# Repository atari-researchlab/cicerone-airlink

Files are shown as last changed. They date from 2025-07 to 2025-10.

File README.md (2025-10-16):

<!-- LICENSE INFORMATION
Copyright (C) 2025 ATARI Research Lab
Permission is granted to copy, distribute and/or modify this document
under the terms of the GNU Free Documentation License, Version 1.3
or any later version published by the Free Software Foundation;
with no Invariant Sections, no Front-Cover Texts, and no Back-Cover Texts.
A copy of the license is included in the section entitled "GNU
Free Documentation License".
-->

<!-- markdownlint-disable MD041 MD013 -->

<p align="center">
  Grant <strong><em>PID2021-126810OB-I00</em></strong> funded by:<br />
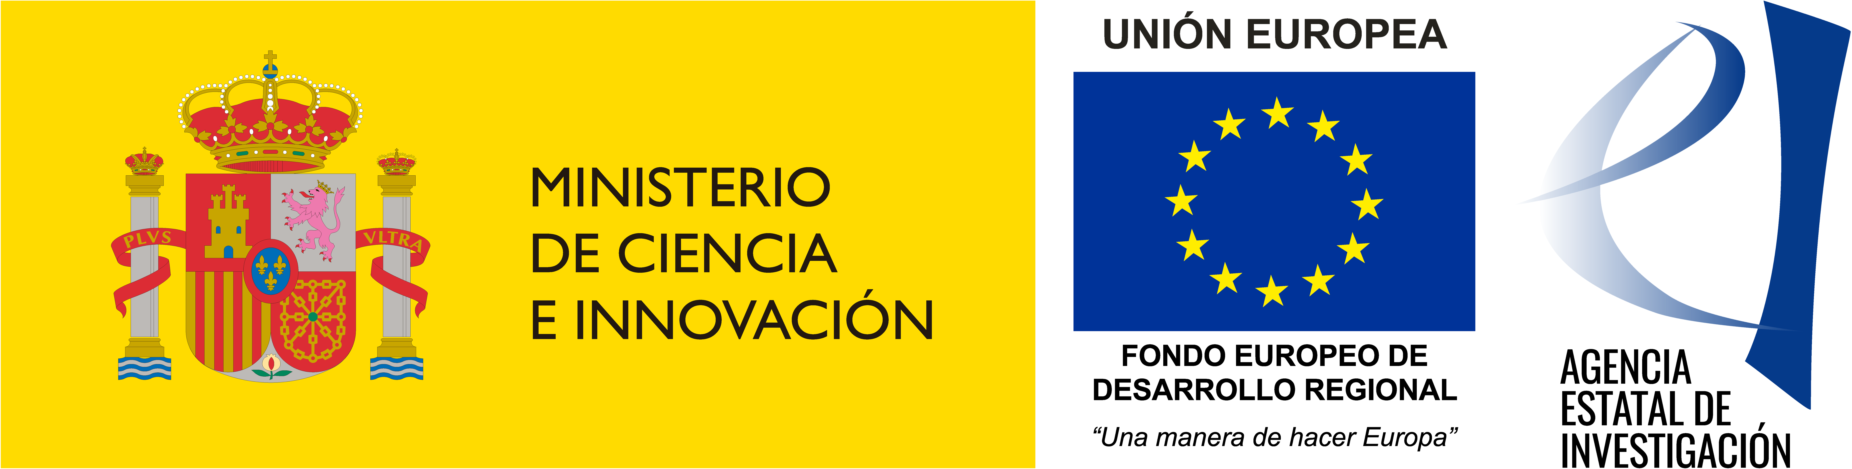
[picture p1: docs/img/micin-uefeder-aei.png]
Funded by Ministerio de Ciencia, Innovación y Universidades, European Union and Agencia Estatal de Investigacion
  <br />
</p>

<p align="center">
  
  
  
  
  
</p>

* * *

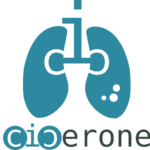
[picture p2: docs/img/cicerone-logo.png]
CICERONE Logo


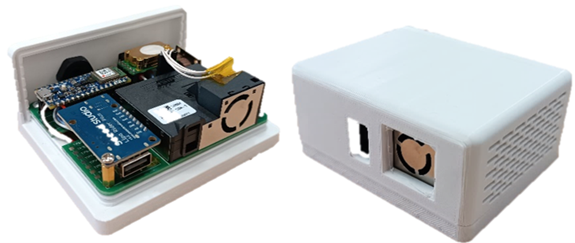
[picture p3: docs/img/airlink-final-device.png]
CICERONE AirLink

<!-- markdownlint-enable MD013 -->

# CICERONE AirLink

CICERONE AirLink© is an indoor air quality telemonitoring device designed for the project CICERONE
(*PID2021-126810OB-I00*).

The air quality device operates by transmitting data every ten minutes for all the parameters
collected by the various sensors, thanks to the communication module created in conjunction with the
RTC. This way, if there are no data transmission failures, a total of 144 daily data points are
obtained for each of the parameters collected by the CO2 and PM/VOCs sensors.

## Table of Contents

<!-- markdownlint-disable MD007 -->
- [CICERONE AirLink](#cicerone-airlink)
  - [Table of Contents](#table-of-contents)
  - [🎓 Features](#-features)
  - [📝 Specifications](#-specifications)
  - [📚 Documentation](#-documentation)
  - [📑 Citations](#-citations)
    - [APA](#apa)
    - [BibTeX](#bibtex)
  - [📃 Licences](#-licences)
<!-- markdownlint-enable MD007 -->

## 🎓 Features

- Sensors for measuring particulate matter (PM1, PM2.5, PM4, and PM10), volatile organic compounds
  (VOCs), carbon dioxide (CO2), temperature, and relative humidity.
- Clock for synchronizing sensor data readings and configuring the data packets to be transmitted.
- Autonomous data transmission independent of the user via an NB-IoT communication module. The
  device includes its own SIM card for sending average sensor values every ten minutes.
- Energy autonomy of up to 5 hours of operation on a fully charged battery.
- Optional cough detection feature using a machine learning algorithm. The device can count the
  number of cough events within a desired time frame.

[Back to top](#top)

## 📝 Specifications

- Electronics
    - Microcontroller
        - Arduino Nano 33 BLE Sense Rev2
    - Sensors
        - PM/VOC
        - CO2
        - Temperature
        - Ambient relative humidity
    - I/O
        - Power switch
    - Communication
        - NB-IoT module (SIM7020G)
    - Others
        - 2-layer custom PCB
        - RTC
        - 900 mAh Lithium-ion battery
        - 5V@1A AC-DC adapter
- Mechanics
    - 3D-printed case
    - Developed in SOLIDWORKS® 2020
- Firmware
    - Sends the data to a server containing 10 minutes average measurements of all sensors via the
      NB-IoT module.
    - Developed in Arduino IDE

[Back to top](#top)

## 📚 Documentation

- [Documentation](https://atari-researchlab.github.io/cicerone-airlink/)
- [Description](https://atari-researchlab.github.io/cicerone-airlink/description/)
    - [Electronics](https://atari-researchlab.github.io/cicerone-airlink/description/electronics/)
    - [Firmware](https://atari-researchlab.github.io/cicerone-airlink/description/firmware/)
- [User guide](https://atari-researchlab.github.io/cicerone-airlink/user-guide/)
    - [Assembly](https://atari-researchlab.github.io/cicerone-airlink/user-guide/assembly/)
    - [Firmware customization](https://atari-researchlab.github.io/cicerone-airlink/user-guide/firmware-configuration/)

[Back to top](#top)

## 📑 Citations

Please consider citing our papers in your publications if the project helps your research.

### APA

``` text
[1] Camacho-Magriñán, P.; Sales-Lerida, D.; León-Jiménez, A.; Sanchez-Morillo, D. Indoor
Environmental Monitoring and Chronic Respiratory Diseases: A Systematic Review. Technologies 2025,
13, 122. https://doi.org/10.3390/technologies13030122
```

``` text
[2] P. Camacho Magriñan, D. Sales Lerida, R. Moreno Mellado, A. Lara Doña, & D. Sánchez Morillo.
(2024). Sistema de telemonitorización de la calidad de aire interior para pacientes con EPOC. XLII
Congreso Anual de la Sociedad Española de Ingeniería Biomédica. CASEIB 2024, 89-92.
```

### BibTeX

``` bibtex
@Article{technologies13030122,
AUTHOR = {Camacho-Magriñán, Patricia and Sales-Lerida, Diego and León-Jiménez, Antonio and
Sanchez-Morillo, Daniel},
TITLE = {Indoor Environmental Monitoring and Chronic Respiratory Diseases: A Systematic Review},
JOURNAL = {Technologies},
VOLUME = {13},
YEAR = {2025},
NUMBER = {3},
ARTICLE-NUMBER = {122},
URL = {https://www.mdpi.com/2227-7080/13/3/122},
ISSN = {2227-7080},
DOI = {10.3390/technologies13030122}
}
```

``` bibtex
@inproceedings{6842c68c8a34bb2df9fc79a9,
title={Sistema de telemonitorización de la calidad de aire interior para pacientes con EPOC},
ISBN={978-84-09-67332-2},
booktitle={XLII Congreso Anual de la Sociedad Española de Ingeniería Biomédica. CASEIB 2024},
publisher={Sociedad Española de Ingeniería Biomédica (SEIB)},
author={P. Camacho Magriñan and D. Sales Lerida and R. Moreno Mellado and A. Lara Doña and D.
Sánchez Morillo},
year={2024},
pages={89-92}
}
```

[Back to top](#top)

## 📃 Licences

All hardware materials and designs, firmware and documentation provided here are licenced under the
following licenses:
<!-- markdownlint-disable MD013 -->
- Hardware: <a href="/hardware/LICENSE.md" target="_blank">Open Source Hardware Logo CERN Open Hardware Licence Version 2 - Strongly Reciprocal</a>
- Firmware source code: <a href="firmware/LICENSE.md" target="_blank">GNU General Public License version 3 or later Logo GNU General Public License version 3 or later</a>
- Documentation: <a href="/docs/LICENSE.md" target="_blank">GNU Free Documentation License, Version 1.3 or later Logo GNU Free Documentation License, Version 1.3 or later</a>

[Back to top](#top)

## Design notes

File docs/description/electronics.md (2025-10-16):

---
title: Electronic design
subtitle:
description:
status:
icon: fontawesome/solid/microchip
---

<!-- LICENSE INFORMATION
Copyright (C) 2025 ATARI Research Lab
Permission is granted to copy, distribute and/or modify this document
under the terms of the GNU Free Documentation License, Version 1.3
or any later version published by the Free Software Foundation;
with no Invariant Sections, no Front-Cover Texts, and no Back-Cover Texts.
A copy of the license is included in the section entitled "GNU
Free Documentation License".
-->

The air quality device consists of a series of components, explained in following table, which shows
the main features of each one.

| Component | Model | Features |
| :---- | :---- | :---- |
| Arduino Nano 33 BLE Sense Rev 2 board **Microcontroller Board** | Arduino Nano 33 BLE Sense Rev 2 | This board was chosen for its integrated microphone, low weight, and multiple sensors (color, proximity, motion, temperature, and humidity, among others). It allows for the connection of communication modules (via UART or I2C) to send real-time data to a server. |
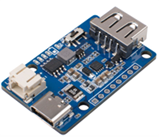
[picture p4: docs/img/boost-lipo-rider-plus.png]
Seeed Studio Boost LiPo Rider Plus board
|  **Battery and power management** | Seeed Studio Boost LiPo Rider Plus | Power and autonomy management for the device from the Seeed Studio brand. It features a 1-cell (3.7V) LiPo battery input and a USB-C connector for 5V power supply. It allows simultaneous battery charging and device powering. It includes a DC-DC boost converter to step up the voltage to 5V, which is needed by other devices like the PM/VOCs sensor and the communication module. |
| Power Supply and LiPo Battery **AC-DC Converter and battery** | 5V@1A Power Supply 900 mAh LiPo Battery | Extra components to provide power via a power supply and/or a battery. |
| DS3231 RTC module **RTC Module** | DFR0641 DS3231M | It ensures reliable synchronization for data collection and for averaging every 10 minutes without accumulating delays. Obtained from the DFRobot brand, it was included because the microcontroller's internal RTC could not be implemented. |
| M5Stack U111 module **NB-IoT Module** | M5Stack U111 | This component from M5Stack was selected for communication because NB-IoT technology offers the best nationwide coverage and can operate without an external access point, using the mobile provider's antennas instead. This type of technology is characterized as LPWA (Low-Power Wide-Area), consuming less power compared to others. This component includes the SIM7020G (SIMCOM) communication module. |
| Amphenol Telaire T6793-5K **CO2 Sensor** | Amphenol Telaire T6793-5K | This NDIR (Non-Dispersive Infrared) optical sensor from Amphenol Advanced Sensor was chosen for CO2 measurement. It has a precision of 400-5000 ppm ± 45 ppm, with a 5-second sampling interval. |
| Sensirio SEN54 sensor **PM and VOCs Sensor** | Sensirion SEN54 | This multisensor from the Sensirion brand is capable of measuring particulate matter (PM), volatile organic compounds (VOCs), temperature, and humidity. For PM measurement, it uses laser wavelength technology (DIN EN 60825-1 Class 1) with a concentration range of 0-1000 µg/m³ and can measure different sizes: PM1.0, PM2.5, PM4, and PM10. Regarding VOCs, it's based on metal oxide sensor technology, with a measurement range of 0-1000 ppm. |

The air quality device ultimately functions by sending all the parameters collected by the
different sensors every ten minutes, thanks to the communication module created in conjunction with
the RTC. This way, if there are no data transmission failures, a total of 144 daily data points are
obtained for each of the parameters collected by the CO2 and SEN54 sensors.

## Schematics

The figure shows the schematic design for connecting the device's various components, serving as
the basis for the necessary PCB design.

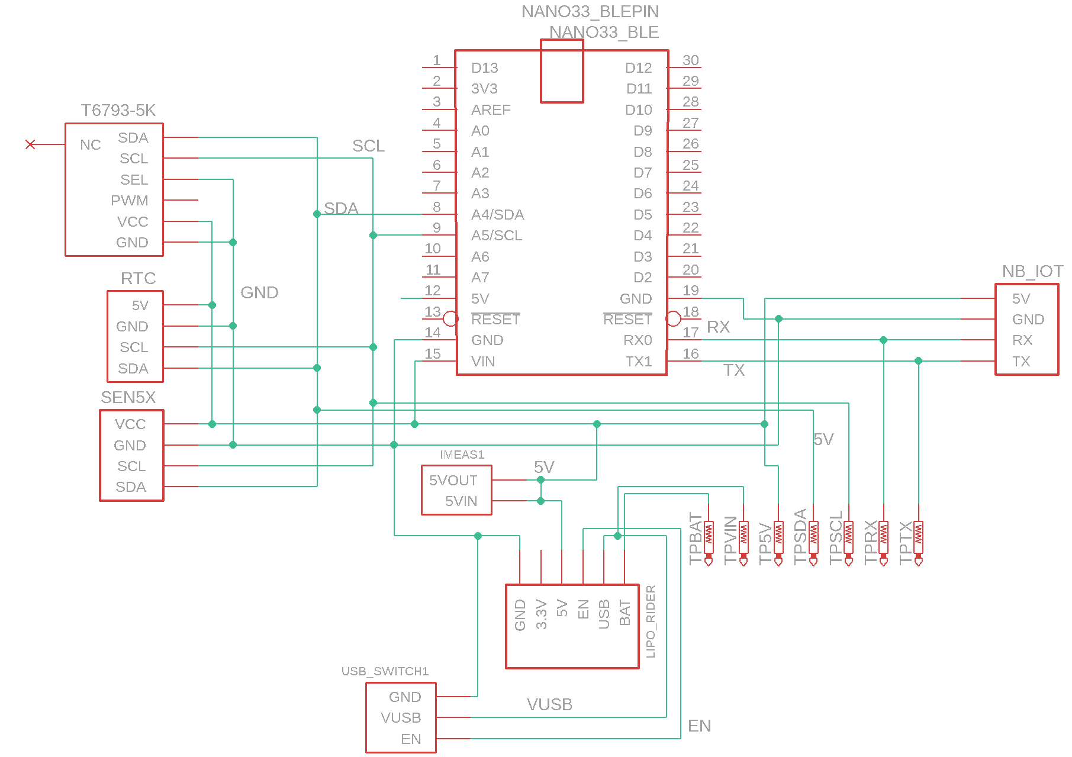
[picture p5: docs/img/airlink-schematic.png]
CICERONE AirLink PCB Schematic


Communication between the micro and the NB-IoT module is done via the UART protocol, using the Tx
and Rx pins. For the rest of the components (sensors and RTC), communication is performed via I2C.
Additionally, all components are powered with 5 volts. A pair of pins were also added to open the
power circuit to allow for physical control and to easily measure power consumption. Thus, the board
design includes traces on both the top and bottom for connecting the different components.

The connectors chosen for connecting the components to the PCB were male and female headers for all
components, except for the NB-IoT module, which used a female connector compatible with the one the
module already had. For this, the Grove Female Header HY2.0-4P, an SMD slide type, was selected to
connect the IoT module from the bottom of the board without taking up excessive space.

## PCB

The figure shows both sides of the PCB. On it, you can see a couple of cutouts that were made on the
board: one for the battery cable to pass through to the charging module (LiPo Rider Plus), and
another to place the RTC vertically (in an "L" shape) and meet the rest of the size limitations.

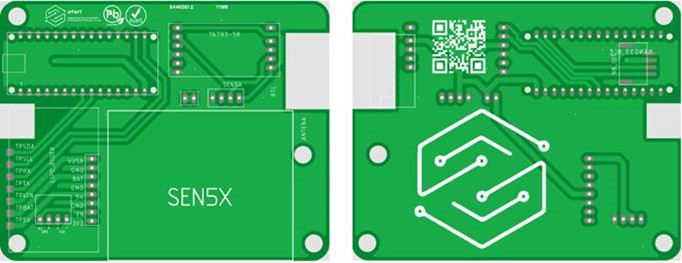
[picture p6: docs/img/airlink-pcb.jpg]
CICERONE Airlink PCB final design


In addition, several pads were added to the PCB, under the position of the charging module, to serve
as test points to check the board's functionality once assembled. A pin jumper was also added to
interrupt the power trace, allowing for a multimeter to be inserted to measure the device's
consumption.

The last set of pins to highlight is a group of 4, also placed under the charging module, whose
purpose is to enable the charging module. A two-position switch was added to this aspect to be able
to cut the power, in case it is not desired to function in any way. The power and GROUND input from
the AC/DC converter are added to two of these 4 pins, and the two wires from the switch are added to
the other two pins to interrupt the voltage path to enable the charging module.

Thus, the assembly of the PCB with the components is shown in the figure, observing that it has been
made with the minimum necessary dimensions to cover the parameters of the different components for
their correct functioning.

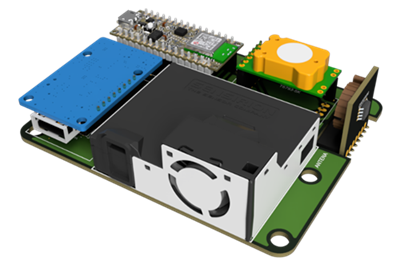
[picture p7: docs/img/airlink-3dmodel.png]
CICERONE Airlink 3D model assembly of the PCB with all additional modules


Finally, the set of components with the PCB is inserted inside a protective casing made with 3D
printing according to the necessary requirements, with special interest in the transit of air flow
and its ergonomics for the intended audience, in addition to those indicated by the different
components themselves.

[microcontroller]: ../img/arduino-nano-33-ble.png
[battery-charger]: ../img/boost-lipo-rider-plus.png
[ac-charger-lipo]: ../img/adaptador-ac-lipo.jpg
[rtc-module]: ../img/dfrobot-ds3231m.jpg
[nb-iot-module]: ../img/m5stack-nbiot-sim7020g.png
[co2-sensor]: ../img/amphenol-t6793-5k.png
[pm-vocs-sensor]: ../img/sensirion-sen54.png
[airlink-schematic]: ../img/airlink-schematic.png
[airlink-pcb]: ../img/airlink-pcb.jpg
[airlink-3dmodel]: ../img/airlink-3dmodel.png

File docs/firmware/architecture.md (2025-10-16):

---
title: Firmware Architecture
subtitle:
description: Internal architecture, modular design, and data flow pipeline
status:
icon: material/sitemap
---

<!-- LICENSE INFORMATION
Copyright (C) 2025 ATARI Research Lab
Permission is granted to copy, distribute and/or modify this document
under the terms of the GNU Free Documentation License, Version 1.3
or any later version published by the Free Software Foundation;
with no Invariant Sections, no Front-Cover Texts, and no Back-Cover Texts.
A copy of the license is included in the section entitled "GNU
Free Documentation License".
-->

## Overview

The CICERONE AirLink firmware implements a non-blocking, timer-based architecture designed for
continuous indoor air quality monitoring with remote telemonitoring capabilities. Built on the
Arduino framework for the **Nano 33 BLE Sense Rev2**, it ensures reliable data collection and
transmission.

## Non-Blocking Timer System

The firmware uses a dual-timer architecture to achieve non-blocking operation:

### 5-Second Timer

**Implementation**: `millis()`-based

**Purpose**: Triggers sensor reading and data accumulation

**Characteristics**:

- Based on Arduino's `millis()` function for microsecond precision
- Non-blocking implementation prevents loop stalls
- Accuracy: ±10ms

**Code Example**:

```cpp
unsigned long current_millis = millis();
if (current_millis - prev_millis >= 5000) {
    prev_millis = current_millis;
    alarma_5s = true;  // Set flag for main loop
}
```

### 10-Minute Timer

**Implementation**: RTC-based

**Purpose**: Triggers data averaging and transmission

**Characteristics**:

- Uses DS3231M RTC for accurate timekeeping independent of microcontroller clock
- Maintains timing accuracy even during long-term deployment
- Accuracy: ±1 second

**Benefits**:

- Survives power cycles (RTC has battery backup)
- Independent of system clock drift
- Accurate over extended periods

## Modular Component Structure

The firmware is organized into logical modules, each with dedicated header and implementation files:

| Module | Files | Purpose | Dependencies |
|---|---|---|---|
| **Main** | `firmware.ino` | Entry point, setup, and main loop | All modules |
| **Configuration** | `Configuracion.h` | Centralized settings (device ID, server, APN) | None |
| **Debug** | `Debug.h` | Multi-level logging macros | None |
| **Alarm System** | `Alarma.h/cpp` | Timer management and data averaging | Sensors, RTC |
| **SEN54 API** | `SEN5X_API.h/cpp` | Particulate matter & VOC sensor interface | Wire (I2C) |
| **T6793 API** | `T6793_API.h/cpp` | CO₂ sensor interface | T67XX driver |
| **T67XX Driver** | `T67XX.h/cpp` | Low-level I2C driver for T6793 | Wire (I2C) |
| **RTC** | `DS3231M.h/cpp` | Real-time clock interface | Wire (I2C) |
| **NB-IoT** | `Transmision_NBIOT.h/cpp` | Network communication module | Serial1 (UART) |
| **DateTime** | `Datetime_helper.h` | Date/time utilities and timezone support | None |

### Module Interaction Diagram

```mermaid
graph TB
    Main[firmware.ino] --> Config[Configuracion.h]
    Main --> Debug[Debug.h]
    Main --> Alarma[Alarma.h/cpp]
    Main --> NbIoT[Transmision_NBIOT.h/cpp]

    Alarma --> SEN5X[SEN5X_API.h/cpp]
    Alarma --> T6793[T6793_API.h/cpp]
    Alarma --> RTC[DS3231M.h/cpp]

    T6793 --> T67XX[T67XX.h/cpp]
    NbIoT --> DateTime[Datetime_helper.h]

    SEN5X --> I2C[Wire Library]
    T67XX --> I2C
    RTC --> I2C
    NbIoT --> UART[Serial1]

    style Main fill:#e3f2fd
    style Config fill:#fff3e0
    style Alarma fill:#e8f5e9
    style NbIoT fill:#f3e5f5
```

## Data Flow Pipeline

The firmware follows a structured data flow from sensor reading to transmission:

```mermaid
graph TD
    A[Sensors] -->|5s interval| B[Read Raw Data]
    B --> C[Accumulate Samples]
    C -->|120 samples| D[Calculate Average]
    D --> E[Format JSON Packet]
    E --> F{NB-IoT Enabled?}
    F -->|Yes| G[HTTP POST]
    F -->|No| H[Serial Output Only]
    G --> I[Server]
    H --> J[Local Monitor]

    style A fill:#e1f5ff
    style D fill:#fff4e1
    style G fill:#e8f5e9
    style I fill:#f3e5f5
```

### Pipeline Stages

#### Stage 1: Sensor Reading (Every 5 seconds)

- Triggered by `alarma_5s` flag
- Reads all sensors via I2C
- Non-blocking implementation

#### Stage 2: Data Accumulation

- Sum values stored in accumulator variables
- Separate counters for different sensor groups
- Floating-point precision maintained

#### Stage 3: Averaging (Every 10 minutes)

- Arithmetic mean: `average = sum / count`
- Triggered by `alarma_10min` flag
- 120 samples (12 per minute × 10 minutes)

#### Stage 4: JSON Formatting

- Builds JSON object with all sensor data
- Includes timestamp from RTC
- Device ID from configuration

#### Stage 5: Transmission

- Conditional on `HABILITAR_NBIOT` setting
- HTTP POST to configured server
- Retry mechanism on failure

## Memory Management

The firmware employs careful memory management strategies to ensure reliable operation within the
constraints of the microcontroller.

### Static Allocation

**Approach**: Most variables are statically allocated

**Benefits**:

- Avoids heap fragmentation
- Predictable memory usage
- Faster execution (no malloc overhead)

**Example**:

```cpp
// Static allocation in Alarma.cpp
float sum_sen5x_mc_2p5 = 0.0f;
float avg_sen5x_mc_2p5 = 0.0f;
uint16_t cont1 = 0;
```

### Accumulator Variables

**Purpose**: Separate sum variables for each sensor parameter

**Structure**:

- `sum_*` - Accumulation variables (reset every 10 minutes)
- `avg_*` - Average variables (calculated every 10 minutes)
- `cont*` - Sample counters

**Memory Impact**: ~50 bytes per sensor parameter

### String Optimization

**Strategy**: Minimize dynamic string operations

**Techniques**:

- Use `F()` macro to store strings in flash memory
- Fixed-size character buffers for serial output
- Avoid String class concatenation in loops

**Example**:

```cpp
// Good: String in flash
Serial.println(F("Sensor initialized"));

// Avoid: Dynamic string allocation
String msg = "Value: " + String(value);  // Creates temporary objects
```

### Buffer Management

**Serial Communication**: 256-byte buffer for debug output

**NB-IoT Communication**: Fixed buffers for AT commands and responses

**JSON Generation**: Pre-allocated buffer (configurable size)

## Memory Usage Summary

| Category | Size | Notes |
|---|---|---|
| **Code (Flash)** | ~100-150 KB | Depends on enabled modules |
| **Global Variables** | ~5-10 KB | Sensor data, accumulators |
| **Stack** | ~2-4 KB | Function calls, local vars |
| **Debug Buffers** | ~256 bytes | When DEBUG_LEVEL > 0 |
| **Available Flash** | ~900 KB | Nano 33 BLE has 1MB flash |
| **Available RAM** | ~240 KB | Nano 33 BLE has 256KB RAM |

!!! success "Memory Efficiency"
    The firmware uses less than 15% of available flash and less than 10% of available RAM, leaving
    plenty of room for future enhancements.

## Conditional Compilation

The firmware uses preprocessor directives to include or exclude features at compile time.

### NB-IoT Module

```cpp
#if HABILITAR_NBIOT
    #include "Transmision_NBIOT.h"

    void loop() {
        if (alarma_10min) {
            nbiot_enviar(json);
        }
    }
#endif
```

**When disabled** (`HABILITAR_NBIOT = 0`):

- All NB-IoT code is removed from binary
- Reduces flash usage by ~30-40 KB
- Eliminates UART communication overhead
- Saves power (no cellular radio)

### Debug System

```cpp
#if DEBUG_LEVEL > 0
    #define DEBUG_ERROR(format, ...) debug_printf("[ERROR]", format, ##__VA_ARGS__)
#else
    #define DEBUG_ERROR(format, ...)  // Expands to nothing
#endif
```

**When disabled** (`DEBUG_LEVEL = 0`):

- All debug code removed (zero overhead)
- Reduces flash usage by ~10-15 KB
- Eliminates string storage in flash
- No serial output

## Benefits of Modular Architecture

### Code Maintainability

- **Separation of Concerns**: Each module has a single responsibility
- **Easy Testing**: Modules can be tested independently
- **Clear Interfaces**: Well-defined function signatures

### Extensibility

- **Add Sensors**: Create new API module following existing patterns
- **New Communication**: Replace NB-IoT with different protocol
- **Custom Processing**: Modify averaging algorithms without affecting sensors

### Debugging

- **Module-Level Debug**: Enable/disable debug per module
- **Isolated Issues**: Easier to identify problematic components
- **Clear Logging**: Debug messages tagged with module name

### Portability

- **Hardware Abstraction**: Sensor APIs abstract I2C details
- **Platform Independence**: Most code portable to other Arduino boards
- **Configuration Centralized**: Easy to adapt to different deployments

## Related Documentation

- [Program Flow](program-flow.md) - Detailed execution flow and state diagrams
- [Sensor Interfaces](sensor-interfaces.md) - Sensor communication protocols
- [Configuration System](../user-guide/firmware-configuration.md) - Device configuration
- [API Reference](api/files.md) - Complete code documentation

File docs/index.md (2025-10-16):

---
title: CICERONE AirLink©
subtitle:
description:
status:
icon: material/home
---

<!-- LICENSE INFORMATION
Copyright (C) 2025 ATARI Research Lab
Permission is granted to copy, distribute and/or modify this document
under the terms of the GNU Free Documentation License, Version 1.3
or any later version published by the Free Software Foundation;
with no Invariant Sections, no Front-Cover Texts, and no Back-Cover Texts.
A copy of the license is included in the section entitled "GNU
Free Documentation License".
-->

<!-- markdownlint-disable MD013-->
<p align="center">
  
  
  
</p>

<p align="center">CICERONE Project Logo CICERONE Logo</p>
<p align="center">CICERONE AirLink Logo CICERONE AirLink </p>
<!-- markdownlint-enable MD013-->
CICERONE AirLink© is an indoor air quality telemonitoring device designed for the project CICERONE
(*PID2021-126810OB-I00*).

The air quality device operates by transmitting data every ten minutes for all the parameters
collected by the various sensors, thanks to the communication module created in conjunction with
the RTC. This way, if there are no data transmission failures, a total of 144 daily data points
are obtained for each of the parameters collected by the CO2 and PM/VOCs sensors.

## :octicons-checklist-16: Features

- Sensors for measuring particulate matter (PM1, PM2.5, PM4, and PM10), volatile organic compounds
  (VOCs), carbon dioxide (CO2), temperature, and relative humidity.
- Clock for synchronizing sensor data readings and configuring the data packets to be transmitted.
- Autonomous data transmission independent of the user via an NB-IoT communication module. The
  device includes its own SIM card for sending average sensor values every ten minutes.
- Energy autonomy of up to 5 hours of operation on a fully charged battery.
- Optional cough detection feature using a machine learning algorithm. The device can count the
  number of cough events within a desired time frame.

## :material-file-link: Citations

--8<-- "./about/citations.md:cite"

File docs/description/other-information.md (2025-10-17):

---
title: Additional information
subtitle:
description:
status:
icon: material/information-variant
---

<!-- LICENSE INFORMATION
Copyright (C) 2025 ATARI Research Lab
Permission is granted to copy, distribute and/or modify this document
under the terms of the GNU Free Documentation License, Version 1.3
or any later version published by the Free Software Foundation;
with no Invariant Sections, no Front-Cover Texts, and no Back-Cover Texts.
A copy of the license is included in the section entitled "GNU
Free Documentation License".
-->

## Energy Consumption

The device's power consumption is calculated by summing the electrical consumption of all
components, including the maximum peak current. The table shows a summary of the energy consumption
involved in the device's operation.

| Name | Max Peak Current (Max) | AVG. Supply Current (typ) |
| :---- | :---- | :---- |
| 1. Sensor SEN54 | 110 mA | 63 mA |
| 2. Sensor T6793-5K | 200 mA | 20 mA |
| 3. Arduino Nano 33 BLE Sense Rev2 | - | 20 mA |
| 4. DFR0641 RTC DS3231M | - | 0.13 mA |
| 5. U111 M5Stack | 700 mA | 5.6 mA |
| **Total** |  | **108.73 mA** |

/// table-caption |<
Modules current consumption and global current
///

The consumption calculated in Table 2 must include the losses caused by the LiPo Rider Plus module's
3.7V to 5V DC-DC converter, which has an efficiency of around 83%. This results in a total
consumption of 131mA. On the other hand, since the selected battery has a capacity of 900mAh,
it's possible to determine the device's autonomy with a simple calculation. The result is
approximately 6 hours of operation without a mains connection.

Another aspect to consider is the NB-IoT module, which has a maximum consumption of 700mA during
transmission. Since the device sends a packet every 10 minutes, the average consumption (on the
order of a few milliamps) is negligible. The rest of the time when it's not transmitting, it has a
residual consumption below one milliamp. However, it is important to know the device's peak
consumption to determine the minimum power supply rating. In this regard, the maximum consumption
will occur during transmission. Therefore, you would add the NB-IoT module's consumption (700mA)
to the consumption calculated in the table (108.73mA) and apply the DC-DC converter's efficiency
factor (83%), resulting in a total of 974 mA. This consumption value is momentary (lasting for a
few seconds during the transmission period) and was calculated by taking limit values at each step.
Therefore, the minimum power supply can be considered to be able to supply 1 ampere of current.

## **Estimated Unit Cost**

The following table shows the different components included in the final device, along with the
vendor name, reference, and cost from the vendor's website. It's important to note that the unit
cost included is for orders of more than 25 units per component.

| Qty | Name | Vendor | Reference | Unit Cost |
| :---- | :---- | :---- | :---- | :---- |
| 1 | Sensirion SEN54 | Mouser Electronics | 403-SEN54-SDN-T | 19.36 € |
| 1 | Amphenol Telaire T6793-5K | Mouser Electronics | 527-T6793-5K | 25.84 € |
| 1 | Arduino Nano 33 BLE Sense Rev2 | Arduino Store | ABX00069 | 30.57 € |
| 1 | DFRobot RTC DS3231M | Mouser Electronics | 426-DFR0641 | 6.43 € |
| 1 | M5Stack U111 (NB-IoT Module) | Mouser Electronics | 170-U111 | 21.30 € |
| 1 | Seeed Studio LiPo Rider Plus | Mouser Electronics | 713-106990290 | 4.59 € |
| 1 | NB-IoT Antenna | Mouser Electronics | 538-146185-0300 | 2.98 € |
| 1 | 5V@1A AC-DC Adapter | Mouser Electronics | 552-AA10E-050A(M)-R | 6.00 € |
| 1 | 3.7V 900 mAh LiPo Battery | BricoGeek | 603048 | 5.95 € |
| 1 | Hex Male-Female M3x12 Standoff | Mouser Electronics | 761-M2107-3005-B | 0.97 € |
| 1 | Rocker Switch (On-Off) | Amazon | - | 0.50 € |
| 1 | PG7 Cable Gland | Amazon | - | 0.65 € |
| 1 | Custom PCB (2-layer) | Eurocircuits | - | 5.00 € |
| 1 | 3D Printed Enclosure | Impresoras3D | 100gr 1.75mm PETG Filament | 1.77 € |
| 1 | 3D Printing Energy Cost | - | - | 0.80 € |
| **Total** |  |  |  | **130.71 €** |

/// table-caption |<
Estimated budget for the final device (unit prices are based on an order of 25 devices as of June 2024).
///

To calculate the cost of the enclosure, the weight of the material used for 3D printing was
accounted for. A total of 103.40 grams of rigid 1.75mm diameter PETG filament from the i3D Tested
brand was used for each enclosure. The price of this filament is €17.11 for a 1-kilogram roll.
Therefore, by using a rule of three, the unit cost shown in the Table is easily obtained. It's
worth mentioning that the energy consumption and wear and tear of the 3D printing equipment have
not been taken into account for the calculation.

Another standard measure for calculating cost is the electrical energy used by the 3D printer. On
average, a 3D printer takes 10 to 15 hours to print 103.40g of material at a standard speed of
55-60mm/s. Considering the price of €0.2136 per kWh in the city of Cádiz, Andalusia, and a typical
3D printer consumption of 0.25 kW, the calculation can be done by simply multiplying these factors.
Assuming the case of highest consumption (15 hours), the total cost would be:

$$
0.25kW \times 15h \times 0.2136 \frac{\unicode{0x20AC}}{kW h} = 0.801 \unicode{0x20AC}
$$

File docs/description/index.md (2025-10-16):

---
title: Device description
subtitle:
description:
status:
icon: material/list-box-outline
---

<!-- LICENSE INFORMATION
Copyright (C) 2025 ATARI Research Lab
Permission is granted to copy, distribute and/or modify this document
under the terms of the GNU Free Documentation License, Version 1.3
or any later version published by the Free Software Foundation;
with no Invariant Sections, no Front-Cover Texts, and no Back-Cover Texts.
A copy of the license is included in the section entitled "GNU
Free Documentation License".
-->

CICERONE Airlink final design

## Overview

The CICERONE AirLink firmware is an embedded system designed for continuous indoor air quality
monitoring with remote telemonitoring capabilities. Built on the Arduino framework for the **Nano 33
BLE Sense Rev2**, the firmware implements a non-blocking, timer-based architecture that ensures
reliable data collection and transmission.

### Key Features

- **Multi-Sensor Integration**: Seamlessly interfaces with SEN54 (particulate matter & VOC) and
  T6793-5K (CO₂) sensors
- **Periodic Data Acquisition**: Sensor readings every 5 seconds with 10-minute averaging cycles
  (144 data points per day)
- **NB-IoT Connectivity**: Optional wireless data transmission via SIM7020G module
- **Real-Time Clock**: Accurate timestamping using DS3231M RTC with battery backup
- **Modular Design**: Clean separation of concerns with dedicated APIs for each component
- **Debug System**: Multi-level logging framework for development and troubleshooting
- **Low Power**: Optimized for battery-powered deployment scenarios
- **Production Ready**: Conditional compilation eliminates unused code for minimal footprint

### Technical Specifications

| Parameter | Value | Notes |
|---|---|---|
| **Platform** | Arduino Mbed OS Nano | Nano 33 BLE Sense Rev2 |
| **Language** | C/C++ | Arduino framework |
| **Compiler** | GCC ARM | Via Arduino CLI |
| **Flash Memory** | ~100-150 KB | Depends on enabled modules |
| **RAM Usage** | ~20-30 KB | Dynamic allocation minimal |
| **Sampling Rate** | 5 seconds | Configurable in code |
| **Averaging Period** | 10 minutes | 120 samples per average |
| **Transmission Interval** | 10 minutes | 144 transmissions/day |

[airlink-final]: ../img/airlink-final-device.png

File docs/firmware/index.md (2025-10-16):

---
title: Firmware Overview
subtitle:
description: Comprehensive firmware documentation for CICERONE AirLink
status:
icon: octicons/file-code-16
---

<!-- LICENSE INFORMATION
Copyright (C) 2025 ATARI Research Lab
Permission is granted to copy, distribute and/or modify this document
under the terms of the GNU Free Documentation License, Version 1.3
or any later version published by the Free Software Foundation;
with no Invariant Sections, no Front-Cover Texts, and no Back-Cover Texts.
A copy of the license is included in the section entitled "GNU
Free Documentation License".
-->

<!-- markdownlint-disable MD033 MD030 -->

## Welcome

The CICERONE AirLink firmware is an embedded system designed for continuous indoor air quality
monitoring with remote telemonitoring capabilities. Built on the Arduino framework for the
**Nano 33 BLE Sense Rev2**, it implements a non-blocking, timer-based architecture that ensures
reliable data collection and transmission.

## Key Features

<div class="grid cards" markdown>

-   :material-timer: **Non-Blocking Architecture**

    ---

    Dual-timer system with 5-second sensor sampling and 10-minute data averaging cycles.

-   :material-gauge: **Multi-Sensor Integration**

    ---

    SEN54 (PM/VOC), T6793-5K (CO₂), and DS3231M RTC for comprehensive air quality monitoring.

-   :material-antenna: **NB-IoT Connectivity**

    ---

    Optional wireless data transmission via SIM7020G module with HTTP POST.

-   :material-puzzle: **Modular Design**

    ---

    Clean separation of concerns with dedicated APIs for each component.

-   :material-bug-check: **Debug System**

    ---

    Multi-level logging framework with per-module configuration.

-   :material-memory: **Memory Efficient**

    ---

    Static allocation, minimal dynamic strings, optimized for long-term deployment.

</div>

## Documentation Sections

### :material-sitemap: [Architecture](architecture.md)

Learn about the system architecture, modular component structure, data flow pipeline, and memory
management strategies.

**Topics covered**:

- Non-blocking timer system (5s and 10min)
- Module organization and dependencies
- Data accumulation and averaging
- Conditional compilation for feature control

[:octicons-arrow-right-24: Read Architecture Documentation](architecture.md)

---

### :material-chart-timeline-variant: [Program Flow](program-flow.md)

Understand the detailed execution flow from device startup through continuous operation.

**Topics covered**:

- Setup phase initialization sequence
- Main loop structure and timing
- 5-second data acquisition cycle
- 10-minute averaging and transmission cycle

[:octicons-arrow-right-24: Read Program Flow Documentation](program-flow.md)

---

### :material-chip: [Sensor Interfaces](sensor-interfaces.md)

Explore sensor communication protocols, specifications, and calibration procedures.

**Topics covered**:

- SEN54 particulate matter and VOC sensor
- T6793-5K CO₂ sensor with ABC algorithm
- DS3231M real-time clock with battery backup
- I2C bus configuration and troubleshooting

[:octicons-arrow-right-24: Read Sensor Documentation](sensor-interfaces.md)

---

### :material-cloud-upload: [Data Transmission](data-transmission.md)

Discover how data is formatted and transmitted via NB-IoT cellular connectivity.

**Topics covered**:

- JSON packet format and generation
- NB-IoT communication protocol (SIM7020G)
- AT command sequences
- Power consumption optimization

[:octicons-arrow-right-24: Read Transmission Documentation](data-transmission.md)

---

## Quick Start

### Building and Uploading

```powershell
# Compile firmware
arduino-cli compile --profile nano33ble --build-path firmware/build firmware/

# Upload to board
arduino-cli upload --profile nano33ble --input-dir firmware/build

# Monitor serial output
arduino-cli monitor -p COM3 -c baudrate=115200
```

See the [project README](https://github.com/atari-researchlab/cicerone-airlink) for detailed
build instructions.

### Configuration

Before uploading, configure the device in `firmware/Configuracion.h`:

```cpp
#define ID_USUARIO "AIRLINK_01"              // Device ID
#define HABILITAR_NBIOT 1                     // Enable NB-IoT
#define SERVIDOR_IP "http://example.com"      // Server URL
#define APN_NBIOT "iot.1nce.net"              // Network APN
```

See [Firmware Configuration Guide](../user-guide/firmware-configuration.md) for detailed
configuration options.

### Debug Output

Enable debug output in `firmware/Debug.h`:

```cpp
#define DEBUG_LEVEL 3        // 0-4 (0=disabled, 3=recommended)
#define DEBUG_SEN5X 3        // Per-module debug levels
#define DEBUG_NBIOT 3
```

See [Debug Configuration Guide](../user-guide/debug-configuration.md) for debugging options.

---

## Technical Specifications

| Parameter | Value | Notes |
|---|---|---|
| **Platform** | Arduino Mbed OS Nano | Nano 33 BLE Sense Rev2 |
| **Language** | C/C++ | Arduino framework |
| **Compiler** | GCC ARM | Via Arduino CLI |
| **Flash Memory** | ~100-150 KB | Depends on enabled modules |
| **RAM Usage** | ~20-30 KB | Dynamic allocation minimal |
| **Sampling Rate** | 5 seconds | Configurable in code |
| **Averaging Period** | 10 minutes | 120 samples per average |
| **Transmission Interval** | 10 minutes | 144 transmissions/day |
| **Power Consumption** | ~120-180 mA | Average (5V input) |
| **Battery Life** | ~5 hours | With 900 mAh battery + NB-IoT |

---

## API Reference

Complete API documentation is available through Doxygen-generated references:

:material-book-open-variant: **[API Documentation](api/files.md)** - Generated from `firmware/`
source code

The API documentation includes:

- Function prototypes and parameters
- Variable definitions and usage
- Module dependencies
- Code examples
- Implementation notes

---

## Additional Resources

### Configuration Guides

- :material-tune: [Firmware Configuration](../user-guide/firmware-configuration.md) - Configure
   device settings
- :material-bug: [Debug Configuration](../user-guide/debug-configuration.md) - Debug system setup

### Hardware Documentation

- :material-chip: [Hardware Description](../description/electronics.md) - PCB design and electronics
- :material-cube-outline: [Enclosure Design](../description/enclosure.md) - 3D model and assembly
- :material-tools: [Assembly Guide](../user-guide/assembly.md) - Physical device assembly

### Project Resources

- :fontawesome-brands-github: [Source Code Repository](https://github.com/atari-researchlab/cicerone-airlink)
- :material-file-document: [Project Documentation](https://atari-researchlab.github.io/cicerone-airlink/)
- :material-email: [Contact & Support](mailto:gruboibt@uca.es)

---

## License

The firmware is licensed under the **GNU General Public License v3.0 or later**.

See [LICENSE.md](https://github.com/atari-researchlab/cicerone-airlink/blob/main/firmware/LICENSE.md)
for full license text.

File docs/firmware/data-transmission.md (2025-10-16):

---
title: Data Transmission
subtitle:
description: Network communication, JSON format, and NB-IoT protocol
status:
icon: material/cloud-upload
---

<!-- LICENSE INFORMATION
Copyright (C) 2025 ATARI Research Lab
Permission is granted to copy, distribute and/or modify this document
under the terms of the GNU Free Documentation License, Version 1.3
or any later version published by the Free Software Foundation;
with no Invariant Sections, no Front-Cover Texts, and no Back-Cover Texts.
A copy of the license is included in the section entitled "GNU
Free Documentation License".
-->

## Overview

The CICERONE AirLink device transmits averaged sensor data every 10 minutes via HTTP POST requests
over NB-IoT cellular connectivity. This page details the data format, network communication
protocol, and transmission process.

## JSON Packet Format

### Structure

Data is transmitted as a JSON object with the following structure:

```json
{
  "device_id": "AIRLINK_01",
  "timestamp": "2025-10-16T14:30:00+02:00",
  "pm1_0": 8.5,
  "pm2_5": 12.3,
  "pm4_0": 15.7,
  "pm10": 18.4,
  "voc_index": 156,
  "nox_index": 0,
  "temperature": 23.5,
  "humidity": 45.2,
  "co2": 687
}
```

### Field Descriptions

| Field | Type | Unit | Description |
|---|---|---|---|
| `device_id` | string | - | Unique device identifier (from `ID_USUARIO`) |
| `timestamp` | string | ISO 8601 | Date/time with timezone offset |
| `pm1_0` | float | µg/m³ | Particulate matter 1.0 micron |
| `pm2_5` | float | µg/m³ | Particulate matter 2.5 micron |
| `pm4_0` | float | µg/m³ | Particulate matter 4.0 micron |
| `pm10` | float | µg/m³ | Particulate matter 10 micron |
| `voc_index` | integer | index | Volatile organic compounds index (1-500) |
| `nox_index` | integer | index | Nitrogen oxides index (typically 0 for SEN54) |
| `temperature` | float | °C | Ambient temperature |
| `humidity` | float | % | Relative humidity |
| `co2` | float | ppm | Carbon dioxide concentration |

### JSON Generation

```cpp
String nbiot_paquete() {
    StaticJsonDocument<512> doc;

    // Device identification
    doc["device_id"] = ID_USUARIO;

    // Timestamp (ISO 8601 with timezone)
    DateTime now = rtc.getRTCTime();
    char timestamp[30];
    snprintf(timestamp, sizeof(timestamp),
             "%04d-%02d-%02dT%02d:%02d:%02d+02:00",
             now.year(), now.month(), now.day(),
             now.hour(), now.minute(), now.second());
    doc["timestamp"] = timestamp;

    // SEN54 sensor data
    doc["pm1_0"] = avg_sen5x_mc_1p0;
    doc["pm2_5"] = avg_sen5x_mc_2p5;
    doc["pm4_0"] = avg_sen5x_mc_4p0;
    doc["pm10"] = avg_sen5x_mc_10p0;
    doc["voc_index"] = (int)avg_sen5x_voc_index;
    doc["nox_index"] = (int)avg_sen5x_nox_index;
    doc["temperature"] = avg_sen5x_temp;
    doc["humidity"] = avg_sen5x_hum;

    // T6793 sensor data
    doc["co2"] = avg_t6793_co2;

    // Serialize to string
    String json;
    serializeJson(doc, json);

    DEBUG_VERBOSE("JSON packet: %s", json.c_str());

    return json;
}
```

### Typical Packet Size

**Size**: 200-250 bytes (varies with floating-point precision)

**Compressed**: ~150-180 bytes (if compression used)

**Daily Data**: ~36 KB (250 bytes × 144 transmissions)

### Timestamp Format

**Standard**: ISO 8601

**Format**: `YYYY-MM-DDTHH:MM:SS±HH:MM`

**Example**: `2025-10-16T14:30:00+02:00`

**Components**:

- Date: `2025-10-16` (October 16, 2025)
- Time: `14:30:00` (2:30:00 PM)
- Timezone: `+02:00` (CEST, 2 hours ahead of UTC)

**Configuration**: Timezone offset defined in `Datetime_helper.h`

## NB-IoT Communication

### Module: SIM7020G

**Manufacturer**: SIMCom

**Technology**: NB-IoT (LTE Cat-NB1)

**Frequency Bands**: B1, B3, B5, B8, B20, B28

**Communication**: UART (Serial1 on Nano 33 BLE)

**Baud Rate**: 115200

**Power**: ~200-300 mA during transmission

### AT Command Protocol

The SIM7020G uses AT commands for configuration and data transmission:

#### Basic Commands

| Command | Purpose | Response |
|---|---|---|
| `AT` | Test connectivity | `OK` |
| `AT+CGATT?` | Check network attachment | `+CGATT: 1` |
| `AT+CSQ` | Signal quality | `+CSQ: 25,99` |
| `AT+CPIN?` | Check SIM card | `+CPIN: READY` |

#### Network Configuration

```cpp
// Attach to network
sendATCommand("AT+CGATT=1");

// Configure APN
String apn_cmd = "AT+CGDCONT=1,\"IP\",\"" + String(APN_NBIOT) + "\"";
sendATCommand(apn_cmd);

// Activate PDP context
sendATCommand("AT+CGACT=1,1");

// Wait for network registration
sendATCommand("AT+CEREG?");
```

#### HTTP Configuration

```cpp
// Set HTTP URL
String url_cmd = "AT+HTTPURL=" + String(url.length());
sendATCommand(url_cmd);
sendATCommand(url);  // Send actual URL

// Set HTTP content type
sendATCommand("AT+HTTPCONTENT=\"application/json\"");

// Prepare to send data
String data_cmd = "AT+HTTPDATA=" + String(json.length()) + ",10000";
sendATCommand(data_cmd);
sendATCommand(json);  // Send JSON data

// Execute HTTP POST
sendATCommand("AT+HTTPACTION=1");  // 1 = POST

// Read response
sendATCommand("AT+HTTPREAD");
```

### Connection Sequence

```mermaid
sequenceDiagram
    participant F as Firmware
    participant M as SIM7020G Module
    participant N as Network
    participant S as Server

    F->>M: AT+CGATT=1 (Attach to network)
    M->>N: Registration request
    N-->>M: Registration complete
    M-->>F: OK

    F->>M: AT+CGDCONT=1,"IP","<APN>"
    M-->>F: OK

    F->>M: AT+CGACT=1,1 (Activate PDP)
    M->>N: Activate context
    N-->>M: Context activated
    M-->>F: OK

    F->>M: AT+HTTPURL=<length>
    F->>M: <URL>
    M-->>F: OK

    F->>M: AT+HTTPDATA=<length>,10000
    F->>M: <JSON data>
    M-->>F: OK

    F->>M: AT+HTTPACTION=1 (POST)
    M->>S: HTTP POST request
    S-->>M: HTTP 200 OK
    M-->>F: +HTTPACTION: 1,200,<length>

    F->>M: AT+HTTPREAD
    M-->>F: +HTTPREAD: <response>
```

### Error Handling

#### Connection Failures

```cpp
bool nbiot_enviar(String json) {
    int retry_count = 0;
    const int max_retries = 3;

    while (retry_count < max_retries) {
        if (nbiot_conectar()) {
            if (nbiot_post(json)) {
                DEBUG_INFO("Transmission successful");
                return true;
            }
        }

        retry_count++;
        DEBUG_WARN("Retry %d/%d", retry_count, max_retries);
        delay(5000);  // Wait before retry
    }

    DEBUG_ERROR("Transmission failed after %d retries", max_retries);
    return false;
}
```

#### Network Registration Issues

**Symptoms**: Module cannot attach to network

**Common Causes**:

- No SIM card or SIM not activated
- Weak signal strength
- Incorrect APN configuration
- Network coverage issue

**Debug Commands**:

```cpp
// Check SIM card
AT+CPIN?
// Expected: +CPIN: READY

// Check signal quality
AT+CSQ
// Expected: +CSQ: 15-31,99 (15-31 = good signal)

// Check network registration
AT+CEREG?
// Expected: +CEREG: 0,1 (registered, home network)
```

#### HTTP Errors

**Common HTTP Status Codes**:

| Code | Meaning | Action |
|---|---|---|
| 200 | OK | Success |
| 400 | Bad Request | Check JSON format |
| 401 | Unauthorized | Check API authentication |
| 404 | Not Found | Verify server URL/endpoint |
| 500 | Server Error | Server issue, retry later |
| 504 | Gateway Timeout | Network issue, retry |

**Handling in Code**:

```cpp
if (http_response == 200) {
    DEBUG_INFO("Data accepted by server");
} else if (http_response == 400) {
    DEBUG_ERROR("Invalid JSON format");
} else if (http_response >= 500) {
    DEBUG_ERROR("Server error, will retry");
} else {
    DEBUG_ERROR("HTTP error: %d", http_response);
}
```

## Power Consumption

### Transmission Power Profile

Typical power consumption during transmission cycle:

```mermaid
graph LR
    A[Idle: 100mA] -->|Network attach| B[Peak: 300mA]
    B -->|HTTP POST| C[Peak: 300mA]
    C -->|Wait response| D[Active: 200mA]
    D -->|Complete| A
```

**Duration**: 30-60 seconds per transmission

**Energy**: ~50-100 mAh per transmission

**Daily**: ~7-14 Ah (144 transmissions)

### Power Optimization Strategies

#### 1. Reduce Transmission Frequency

```cpp
// Change from 10 minutes to 30 minutes
if (now.minute() % 30 == 0) {  // Saves ~66% power
    alarma_10min = true;
}
```

#### 2. Optimize Network Attachment

```cpp
// Keep network attached between transmissions
// (avoids re-registration overhead)
```

## Server Requirements

### API Endpoint

**Method**: POST

**Content-Type**: `application/json`

**Encoding**: UTF-8

**Example cURL**:

```bash
curl -X POST https://iot.example.com:64340/aqindoor \
  -H "Content-Type: application/json" \
  -d '{
    "device_id": "AIRLINK_01",
    "timestamp": "2025-10-16T14:30:00+02:00",
    "pm2_5": 12.3,
    "co2": 687,
    ...
  }'
```

### Expected Response

**Success**:

```json
{
  "status": "ok",
  "message": "Data received",
  "device_id": "AIRLINK_01",
  "timestamp": "2025-10-16T14:30:00+02:00"
}
```

**Status Code**: 200 OK

### Server-Side Processing

**Recommended Validations**:

1. **Device ID**: Verify device is registered
2. **Timestamp**: Check if timestamp is reasonable (not too old/future)
3. **Data Ranges**: Validate sensor values are within expected ranges
4. **Duplicate Detection**: Check if packet already received (timestamp + device_id)

**Example Validation** (pseudo-code):

```python
def validate_data(packet):
    # Check device ID
    if not is_device_registered(packet['device_id']):
        return 401, "Unauthorized device"

    # Check timestamp
    timestamp = parse_iso8601(packet['timestamp'])
    if abs(now() - timestamp) > timedelta(hours=1):
        return 400, "Timestamp out of range"

    # Check data ranges
    if not (0 <= packet['pm2_5'] <= 1000):
        return 400, "Invalid PM2.5 value"

    if not (400 <= packet['co2'] <= 5000):
        return 400, "Invalid CO2 value"

    # Store in database
    db.insert(packet)

    return 200, "OK"
```

## Configuration

### Device Configuration

In `Configuracion.h`:

```cpp
// Enable/disable NB-IoT
#define HABILITAR_NBIOT 1

// Server configuration
#define SERVIDOR_IP "http://iot.example.com"
#define SERVIDOR_PUERTO "64340"
#define SERVIDOR_API "/aqindoor"

// Network provider
#define APN_NBIOT "iot.1nce.net"
```

See [Firmware Configuration](../user-guide/firmware-configuration.md) for detailed configuration guide.

### Timezone Configuration

In `Datetime_helper.h`:

```cpp
// Timezone offset (hours)
#define TZ_OFFSET +2  // CEST (Central European Summer Time)
```

## Testing

### Serial Monitor Testing

Disable NB-IoT and test JSON generation:

```cpp
#define HABILITAR_NBIOT 0  // Disable transmission
#define DEBUG_LEVEL 4      // Enable verbose output
```

**Expected Output**:

```text
[INFO][610234][ALARMA] Calculating averages... (120 samples)
[VERBO][610235][NBIOT] JSON packet: {"device_id":"AIRLINK_01","timestamp":"2025-10-16T14:30:00+02:00",...}
```

### Local Server Testing

Use Python to create a simple test server:

```python
from flask import Flask, request, jsonify

app = Flask(__name__)

@app.route('/aqindoor', methods=['POST'])
def receive_data():
    data = request.json
    print(f"Received from {data['device_id']}:")
    print(f"  Timestamp: {data['timestamp']}")
    print(f"  PM2.5: {data['pm2_5']} µg/m³")
    print(f"  CO2: {data['co2']} ppm")
    return jsonify({"status": "ok"}), 200

if __name__ == '__main__':
    app.run(host='0.0.0.0', port=64340)
```

### Network Testing Tools

**AT Command Testing**:

```cpp
// In setup(), add manual AT commands
Serial1.begin(115200);
Serial1.println("AT");
delay(1000);
while (Serial1.available()) {
    Serial.write(Serial1.read());
}
```

**Signal Strength**:

```cpp
sendATCommand("AT+CSQ");
// Response: +CSQ: <rssi>,<ber>
// rssi: 0-31 (higher is better), 99 = unknown
// ber: bit error rate, 99 = unknown
```

## Troubleshooting

### No Network Registration

**Check**:

1. SIM card inserted and activated
2. APN configured correctly
3. Network coverage in area
4. Module powered properly (5V, sufficient current)

**Commands**:

```text
AT+CPIN?      → Check SIM status
AT+CSQ        → Check signal strength
AT+CEREG?     → Check network registration
AT+COPS?      → Check operator selection
```

### JSON Format Errors

**Symptoms**: Server returns 400 Bad Request

**Solutions**:

1. Verify JSON with online validator
2. Check for invalid characters
3. Ensure proper escaping of special characters
4. Validate float formatting (avoid NaN or Inf)

### Transmission Timeouts

**Symptoms**: Module doesn't respond to AT commands

**Solutions**:

1. Increase timeout values
2. Check UART baud rate (115200)
3. Verify Serial1 connections (TX/RX not swapped)
4. Reset module with power cycle

## Related Documentation

- [Program Flow](program-flow.md) - When and how transmission occurs
- [Sensor Interfaces](sensor-interfaces.md) - Data source for JSON packets
- [Firmware Configuration](../user-guide/firmware-configuration.md) - Configuring transmission settings
- [Architecture](architecture.md) - System overview

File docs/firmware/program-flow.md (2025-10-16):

---
title: Program Flow
subtitle:
description: Execution flow, state diagrams, and operational logic
status:
icon: material/chart-timeline-variant
---

<!-- LICENSE INFORMATION
Copyright (C) 2025 ATARI Research Lab
Permission is granted to copy, distribute and/or modify this document
under the terms of the GNU Free Documentation License, Version 1.3
or any later version published by the Free Software Foundation;
with no Invariant Sections, no Front-Cover Texts, and no Back-Cover Texts.
A copy of the license is included in the section entitled "GNU
Free Documentation License".
-->

## Overview

The CICERONE AirLink firmware executes in two distinct phases: **Setup** (initialization) and
**Main Loop** (continuous operation). This page details the execution flow and logic for both phases.

## Setup Phase

<!-- markdownlint-disable MD046 -->
??? "Setup Phase Diagram"

    ``` mermaid
        flowchart TD

        n1["Start"] --> rtc_init
        rtc_init["Initialize RTC and periodic alarms"] --> t6793_init["Initialize T6793 CO₂ sensor"]
        t6793_init --> sen5x_init["Initialize SEN54 PM/VOC sensor"]
        sen5x_init --> if_nbiot{"Enable NB-IoT?"}
        if_nbiot -- Yes --> nbiot_init["Initialize NB-IoT module SIM7020G"]
        if_nbiot -- No --> setup_done("Setup Complete")
        nbiot_init --> setup_done

        n1@{ shape: start}

        class n1,setup_done final;
        classDef default stroke-width:1px, stroke-dasharray:none, stroke:#374D7C, fill:#E2EBFF, color:#000000
        classDef final stroke-width:4px, stroke-dasharray: 0, stroke:#00C853, fill:#C8E6C9, color:#000000
    ```
<!-- markdownlint-enable MD046 -->

### Execution Sequence

The `setup()` function executes once at power-on or reset:

#### 1. Serial Communication

```cpp
#if DEBUG_LEVEL > 0
    Serial.begin(115200);
    while (!Serial) {
        ; // Wait for serial port to connect
    }
    DEBUG_INFO("CICERONE AirLink starting...");
#endif
```

**Purpose**: Initialize UART for debug output

**Baud Rate**: 115200

**Conditional**: Only if `DEBUG_LEVEL > 0`

#### 2. RTC Initialization

```cpp
rtc_inicializar();
rtc_alarma_inicializar();
```

**Purpose**: Configure DS3231M real-time clock

**Tasks**:

- Verify I2C communication
- Set initial time (if needed)
- Configure 10-minute alarm schedule
- Enable alarm interrupts

**Critical**: If RTC fails, system halts (time is essential)

#### 3. T6793 CO₂ Sensor Initialization

```cpp
t6793_inicializar();
```

**Purpose**: Initialize Telaire T6793-5K CO₂ sensor

**Tasks**:

- Configure I2C communication (address 0x15)
- Verify sensor response
- Set measurement mode
- Wait for sensor stabilization

**Fallback**: Continue if sensor fails (log error, skip readings)

#### 4. SEN54 Sensor Initialization

```cpp
sen5x_inicializar();
```

**Purpose**: Initialize Sensirion SEN54 PM/VOC sensor

**Tasks**:

- Configure I2C communication (address 0x69)
- Soft reset sensor
- Start measurement mode
- Wait for warm-up period (~30 seconds for VOC accuracy)

**Fallback**: Continue if sensor fails (log error, skip readings)

#### 5. NB-IoT Initialization (Conditional)

```cpp
#if HABILITAR_NBIOT
    nbiot_inicializar();
#endif
```

**Purpose**: Initialize SIM7020G NB-IoT module

**Tasks**:

- Configure UART communication (Serial1)
- Send AT commands to module
- Verify SIM card detection
- Register with network (may take 30-60 seconds)
- Configure APN settings

**Conditional**: Only if `HABILITAR_NBIOT = 1`

**Fallback**: Continue if fails (log error, local logging only)

### Initialization Order Rationale

The specific order (RTC → T6793 → SEN54 → NB-IoT) ensures:

1. **Timing First**: RTC must be functional before scheduling data collection
2. **Sensors Before Network**: Sensors need warm-up time during network registration
3. **Critical to Optional**: Essential components before optional features
4. **Fast to Slow**: Quick initializations before time-consuming network setup

### Typical Setup Duration

| Component | Duration | Notes |
|---|---|---|
| Serial | <100ms | Nearly instant |
| RTC | ~200ms | I2C communication + config |
| T6793 | ~500ms | Sensor wake-up |
| SEN54 | ~1-2s | Soft reset + measurement start |
| NB-IoT | 30-60s | Network registration varies |
| **Total** | **~35-65s** | Mostly network registration |

!!! tip "Reducing Setup Time"
    During development, disable NB-IoT (`HABILITAR_NBIOT = 0`) to reduce setup time to ~3-5 seconds.

## Main Loop Phase

<!-- markdownlint-disable MD046-->
??? "Main Loop Diagram"

    ``` mermaid
        flowchart TB

        setup_done["Setup"] --> check_alarm_5s["Check if 5 seconds have elapsed"]
        check_alarm_5s --> check_alarm_10min["Check if 10 minutes have elapsed"]
        check_alarm_10min --> if_alarm_5s{"5-second flag active?"}
        if_alarm_5s -- No --> if_alarm_10min{"10-minute flag active?"}
        if_alarm_5s -- Yes --> accumulate_data["Read sensors and accumulate data"]
        accumulate_data --> reset_alarm_5s["Reset 5-second flag"]
        reset_alarm_5s --> if_alarm_10min

        if_alarm_10min -- No --> check_alarm_5s
        if_alarm_10min -- Yes --> average_data["Calculate average of accumulated readings"]
        average_data --> if_nbiot2{"Enable NB-IoT?"}
        if_nbiot2 -- No --> reset_alarm_10min
        if_nbiot2 -- Yes --> transmit_data["Transmit averaged data via HTTP POST"]
        transmit_data --> reset_alarm_10min["Reset 10-minute flag and counters"]
        reset_alarm_10min --> check_alarm_5s

        setup_done:::final

        classDef default stroke-width:1px, stroke-dasharray:none, stroke:#374D7C, fill:#E2EBFF, color:#000000
        classDef final stroke-width:4px, stroke-dasharray: 0, stroke:#00C853, fill:#C8E6C9, color:#000000
    ```
<!-- markdownlint-enable MD046-->

### Main Loop Structure

The `loop()` function runs continuously with minimal blocking:

```cpp
void loop() {
    // Check timers
    check_alarma_5s();
    check_alarma_10min();

    // Handle 5-second cycle
    if (alarma_5s) {
        acumular_datos();
        alarma_5s = false;
    }

    // Handle 10-minute cycle
    if (alarma_10min) {
        promediar_datos();

        #if HABILITAR_NBIOT
            String json = nbiot_paquete();
            nbiot_enviar(json);
        #endif

        alarma_10min = false;
    }
}
```

## 5-Second Cycle (Data Acquisition)

```cpp
void check_alarma_5s() {
    unsigned long current_millis = millis();

    if (current_millis - prev_millis_5s >= 5000) {
        prev_millis_5s = current_millis;
        alarma_5s = true;
    }
}
```

**Non-blocking**: Function returns immediately

**Accuracy**: ±10ms (millis() resolution)

**Overflow Handling**: Subtraction math handles millis() rollover (every 49.7 days)

### Data Accumulation

```cpp
void acumular_datos() {
    DEBUG_VERBOSE("Reading sensors...");

    // Read SEN54 sensor
    if (sen5x_leer()) {
        sum_sen5x_mc_1p0 += sen5x_mc_1p0;
        sum_sen5x_mc_2p5 += sen5x_mc_2p5;
        sum_sen5x_mc_4p0 += sen5x_mc_4p0;
        sum_sen5x_mc_10p0 += sen5x_mc_10p0;
        sum_sen5x_voc_index += sen5x_voc_index;
        sum_sen5x_temp += sen5x_temp;
        sum_sen5x_hum += sen5x_hum;
        cont1++;
    }

    // Read T6793 sensor
    if (t6793_leer()) {
        sum_t6793_co2 += t6793_co2;
        cont2++;
    }

    DEBUG_VERBOSE("Samples: SEN54=%d, T6793=%d", cont1, cont2);
}
```

### Accumulation Strategy

**Separate Counters**: `cont1` (SEN54) and `cont2` (T6793)

**Rationale**:

- Sensors may have different reliability
- Failed reads don't corrupt averages
- Allows for different sampling rates

**Floating-Point Precision**: All accumulation uses `float` to preserve decimal places

**Error Handling**: Failed sensor reads skip accumulation (counter not incremented)

### Expected Sample Count

Over 10 minutes:

- **Target**: 120 samples per sensor (12/minute × 10 minutes)
- **Typical**: 118-120 samples (some reads may fail)
- **Minimum Acceptable**: 100 samples (if below, may indicate sensor issue)

## 10-Minute Cycle (Averaging & Transmission)

```cpp
void check_alarma_10min() {
    DateTime now = rtc.getRTCTime();

    // Check if current minute is multiple of 10
    if (now.minute() % 10 == 0 && now.second() < 5) {
        if (!alarm_10min_triggered) {
            alarma_10min = true;
            alarm_10min_triggered = true;
        }
    } else {
        alarm_10min_triggered = false;  // Reset for next 10-minute mark
    }
}
```

**RTC-Based**: Uses real-time clock, not millis()

**Accuracy**: ±1 second

**Trigger Points**: :00, :10, :20, :30, :40, :50 of each hour

**Debounce**: `alarm_10min_triggered` prevents multiple triggers

### Data Averaging

```cpp
void promediar_datos() {
    DEBUG_INFO("Calculating averages...");

    // Calculate SEN54 averages
    if (cont1 > 0) {
        avg_sen5x_mc_1p0 = sum_sen5x_mc_1p0 / cont1;
        avg_sen5x_mc_2p5 = sum_sen5x_mc_2p5 / cont1;
        avg_sen5x_mc_4p0 = sum_sen5x_mc_4p0 / cont1;
        avg_sen5x_mc_10p0 = sum_sen5x_mc_10p0 / cont1;
        avg_sen5x_voc_index = sum_sen5x_voc_index / cont1;
        avg_sen5x_temp = sum_sen5x_temp / cont1;
        avg_sen5x_hum = sum_sen5x_hum / cont1;
    }

    // Calculate T6793 averages
    if (cont2 > 0) {
        avg_t6793_co2 = sum_t6793_co2 / cont2;
    }

    // Get timestamp from RTC
    DateTime now = rtc.getRTCTime();
    fecha = formatDate(now);
    hora = formatTime(now);

    DEBUG_INFO("PM2.5: %.2f, CO2: %.0f", avg_sen5x_mc_2p5, avg_t6793_co2);
}
```

### Averaging Algorithm

**Method**: Simple arithmetic mean

**Formula**: `average = sum / count`

**Advantages**:

- Memory-efficient (no array storage needed)
- Computationally simple
- Suitable for air quality data (outliers are rare)

**Alternative Approaches** (not implemented):

- Median filtering (requires storing all samples)
- Weighted average (more complex, minimal benefit)
- Outlier rejection (adds complexity, sensor failures already handled)

### Reset Accumulators

```cpp
void reset_accumulators() {
    // Reset SEN54 sums
    sum_sen5x_mc_1p0 = 0.0f;
    sum_sen5x_mc_2p5 = 0.0f;
    // ... (all other sums)

    // Reset counters
    cont1 = 0;
    cont2 = 0;
}
```

**When**: After transmission (or averaging if NB-IoT disabled)

**Purpose**: Prepare for next 10-minute cycle

**Critical**: Must reset to avoid overflow and incorrect averages

### Data Transmission

```cpp
#if HABILITAR_NBIOT
    String json = nbiot_paquete();
    bool success = nbiot_enviar(json);

    if (success) {
        DEBUG_INFO("Data transmitted successfully");
    } else {
        DEBUG_ERROR("Transmission failed");
    }
#endif
```

**Conditional**: Only if `HABILITAR_NBIOT = 1`

**JSON Format**: See [Data Transmission](data-transmission.md)

**Retry Logic**: Handled within `nbiot_enviar()`

**Duration**: 30-60 seconds typically

## Timing Characteristics

### 5-Second Cycle

| Metric | Value | Notes |
|---|---|---|
| **Interval** | 5000ms | Configurable in code |
| **Accuracy** | ±10ms | Based on millis() |
| **Duration** | ~100-200ms | Sensor I2C reads |
| **Blocking** | Minimal | I2C reads are brief |
| **CPU Usage** | <5% | Most time idle |

### 10-Minute Cycle

| Metric | Value | Notes |
|---|---|---|
| **Interval** | 600s (10 min) | Based on RTC |
| **Accuracy** | ±1s | RTC precision |
| **Duration** | 30-60s | Mostly NB-IoT transmission |
| **Blocking** | Significant | AT commands wait for response |
| **CPU Usage** | ~80% | During transmission |

### Daily Operation

- **Data Points**: 144 per day (1 every 10 minutes)
- **Sensor Readings**: 17,280 per day (144 × 120 samples)
- **Transmissions**: 144 per day (if NB-IoT enabled)
- **Total Uptime**: 24 hours (no sleep modes)

## Error Handling During Operation

### Sensor Read Failures

**Strategy**: Skip sample, continue operation

```cpp
if (!sen5x_leer()) {
    DEBUG_WARN("SEN5X read failed, skipping sample");
    // Counter not incremented, sum not updated
    return;
}
```

**Impact**: Slight reduction in sample count (e.g., 118 instead of 120)

**Recovery**: Automatically retries next 5-second cycle

### RTC Failures

**Strategy**: Halt or use backup timing

```cpp
if (!rtc.isRunning()) {
    DEBUG_ERROR("RTC stopped, check battery");
    // Option 1: Halt (safe but stops data collection)
    while(1);

    // Option 2: Fall back to millis() timing (less accurate)
    use_millis_timing = true;
}
```

**Critical**: RTC failure affects timestamps (data integrity issue)

### NB-IoT Transmission Failures

**Strategy**: Log error, continue to next cycle

```cpp
if (!nbiot_enviar(json)) {
    DEBUG_ERROR("Transmission failed, data lost");
    // Data is lost (no local storage)
    // Next 10-minute cycle will try again with new data
}
```

**Impact**: Data gap on server

## Performance Monitoring

### Debug Output Example

```text
[INFO][5012][MAIN] Setup complete
[VERBO][10234][ALARMA] Reading sensors... (sample 1/120)
[VERBO][15234][ALARMA] Reading sensors... (sample 2/120)
...
[INFO][610234][ALARMA] Calculating averages... (120 samples)
[INFO][610235][ALARMA] PM2.5: 12.34, CO2: 687
[INFO][610250][NBIOT] Transmitting data...
[INFO][645123][NBIOT] Transmission successful (response: 200 OK)
```

## Related Documentation

- [Architecture](architecture.md) - System architecture and modular design
- [Data Transmission](data-transmission.md) - Network communication details
- [Sensor Interfaces](sensor-interfaces.md) - Sensor communication protocols
- [Debug Configuration](../user-guide/debug-configuration.md) - Debug system setup

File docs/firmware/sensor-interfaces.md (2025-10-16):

---
title: Sensor Interfaces
subtitle:
description: Sensor communication protocols, specifications, and calibration
status:
icon: material/chip
---

<!-- LICENSE INFORMATION
Copyright (C) 2025 ATARI Research Lab
Permission is granted to copy, distribute and/or modify this document
under the terms of the GNU Free Documentation License, Version 1.3
or any later version published by the Free Software Foundation;
with no Invariant Sections, no Front-Cover Texts, and no Back-Cover Texts.
A copy of the license is included in the section entitled "GNU
Free Documentation License".
-->

<!-- markdownlint-disable MD024 -->

## Overview

The CICERONE AirLink device integrates three primary sensors for comprehensive air quality
monitoring. All sensors communicate via I2C protocol, sharing the same bus with different addresses.

## I2C Bus Configuration

**Bus**: Wire (Arduino standard I2C library)

**Speed**: 100 kHz (standard mode)

**Pull-ups**: External 4.7kΩ resistors on PCB

**Voltage**: 5V logic level (with level shifters if needed)

### I2C Address Map

| Device | Address | Conflict Resolution |
|---|---|---|
| SEN54 | 0x69 | Fixed by manufacturer |
| T6793 | 0x15 | Configurable (factory default) |
| DS3231M | 0x68 | Fixed by manufacturer |

!!! success "No Address Conflicts"
    All I2C devices use different addresses, avoiding conflicts on the shared bus.

## SEN54 Particulate Matter & VOC Sensor

### Specifications

**Manufacturer**: Sensirion

**Model**: SEN54

**Communication**: I2C (address 0x69)

**Supply Voltage**: 4.5-5.5V

**Power Consumption**: ~60 mA typical

**Warm-up Time**: ~30 seconds for VOC accuracy

### Measured Parameters

| Parameter | Range | Accuracy | Units |
|---|---|---|---|
| **PM1.0** | 0-1000 | ±10 µg/m³ | µg/m³ |
| **PM2.5** | 0-1000 | ±10 µg/m³ | µg/m³ |
| **PM4.0** | 0-1000 | ±25 µg/m³ | µg/m³ |
| **PM10** | 0-1000 | ±25 µg/m³ | µg/m³ |
| **VOC Index** | 1-500 | - | Index |
| **Temperature** | -10 to 50 | ±0.5°C | °C |
| **Humidity** | 0-100 | ±4.5% RH | % |

### Library

**Name**: Sensirion I2C SEN5X

**Version**: 0.3.0 (official from Sensirion)

**Installation**:

```bash
arduino-cli lib install "Sensirion I2C SEN5X" "Sensirion Core"
```

### Initialization Sequence

```cpp
bool sen5x_inicializar() {
    Wire.begin();
    sen5x.begin(Wire);

    // Soft reset
    error = sen5x.deviceReset();
    if (error) {
        DEBUG_ERROR("SEN5X reset failed");
        return false;
    }

    delay(100);  // Wait for reset

    // Start measurement
    error = sen5x.startMeasurement();
    if (error) {
        DEBUG_ERROR("Failed to start measurement");
        return false;
    }

    DEBUG_INFO("SEN5X initialized successfully");
    return true;
}
```

### Reading Data

```cpp
bool sen5x_leer() {
    uint16_t error;

    error = sen5x.readMeasuredValues(
        sen5x_mc_1p0,
        sen5x_mc_2p5,
        sen5x_mc_4p0,
        sen5x_mc_10p0,
        sen5x_hum,
        sen5x_temp,
        sen5x_voc_index,
        sen5x_nox_index
    );

    if (error) {
        DEBUG_WARN("SEN5X read error: %d", error);
        return false;
    }

    DEBUG_VERBOSE("PM2.5: %.2f, VOC: %d, Temp: %.1f°C",
                  sen5x_mc_2p5, sen5x_voc_index, sen5x_temp);

    return true;
}
```

### VOC Index Explained

**Scale**: 1-500 (100 = neutral)

**Interpretation**:

- **1-100**: Clean air
- **100-200**: Moderate VOC levels
- **200-300**: Elevated VOC levels
- **300-500**: High VOC levels

**Algorithm**: Sensirion's proprietary VOC algorithm adapts to environment over 12-24 hours

**Initial Values**: May be unreliable for first ~30 seconds after power-on

### Troubleshooting

**Sensor Not Responding**:

1. Check I2C connections (SDA, SCL, GND, VCC)
2. Verify 5V power supply
3. Check I2C address with scanner
4. Ensure sensor is properly seated

**Incorrect Readings**:

1. Allow 30-second warm-up for VOC
2. Check for physical obstructions blocking air inlet
3. Verify sensor is not exposed to extreme temperatures

**Communication Errors**:

```text
[WARN][5012][SEN5X] SEN5X read error: 4
```

**Common Error Codes**:

- `1`: I2C communication timeout
- `2`: Checksum error (data corruption)
- `4`: Sensor not ready (still warming up)

## T6793-5K CO₂ Sensor

### Specifications

**Manufacturer**: Amphenol Advanced Sensors (Telaire)

**Model**: T6793-5K

**Communication**: I2C (address 0x15)

**Supply Voltage**: 4.5-5.5V

**Power Consumption**: ~35 mA typical

**Warm-up Time**: <60 seconds

**Measurement Range**: 0-5000 ppm CO₂

**Accuracy**: ±(50 ppm + 5% of reading)

### Technology

**Method**: Non-Dispersive Infrared (NDIR)

**Calibration**: ABC (Automatic Baseline Correction)

**Expected Lifetime**: >15 years

### Custom Driver

Since there's no official Arduino library, we implement a custom driver:

**Files**: `T67XX.h` / `T67XX.cpp` and `T6793_API.h` / `T6793_API.cpp`

**Features**:

- Low-level I2C communication
- Command/response protocol
- Error detection

### Initialization Sequence

```cpp
bool t6793_inicializar() {
    // Initialize sensor object
    airSensor.begin(Wire);

    // Verify communication
    if (!airSensor.isConnected()) {
        DEBUG_ERROR("T6793 not detected");
        return false;
    }

    // Enable ABC algorithm
    airSensor.setABC(true);

    DEBUG_INFO("T6793 initialized successfully");
    return true;
}
```

### Reading Data

```cpp
bool t6793_leer() {
    t6793_co2 = airSensor.getCO2();

    if (t6793_co2 < 0) {
        DEBUG_WARN("T6793 read error");
        return false;
    }

    DEBUG_VERBOSE("CO2: %.0f ppm", t6793_co2);

    return true;
}
```

### ABC Algorithm

**Purpose**: Automatic calibration to 400 ppm (outdoor CO₂ level)

**Operation**:

- Monitors minimum CO₂ values over 24-hour periods
- Assumes sensor is periodically exposed to fresh air
- Gradually adjusts baseline to account for sensor drift

**Requirements**:

- Device should see fresh air at least once per day
- Not suitable for continuously sealed environments
- Can be disabled if manual calibration preferred

**Configuration**:

```cpp
airSensor.setABC(true);   // Enable ABC (recommended)
airSensor.setABC(false);  // Disable ABC (manual calibration)
```

### Typical CO₂ Levels

| Environment | CO₂ Level | Air Quality |
|---|---|---|
| **Outdoor** | 400 ppm | Baseline |
| **Well-ventilated room** | 400-600 ppm | Excellent |
| **Occupied room** | 600-1000 ppm | Good |
| **Poorly ventilated** | 1000-2000 ppm | Poor |
| **Very poor ventilation** | >2000 ppm | Unhealthy |

### Troubleshooting

**Sensor Not Detected**:

1. Verify I2C address (0x15)
2. Check power supply (5V)
3. Ensure proper I2C connections

**Unrealistic Readings**:

1. Allow 60-second warm-up after power-on
2. Verify sensor is not in sealed enclosure
3. Check for calibration issues

**Calibration Issues**:

If ABC is enabled but readings seem incorrect:

```cpp
// Manual calibration to 400 ppm (expose to fresh outdoor air)
airSensor.calibrateSingle(400);
```

## DS3231M Real-Time Clock

### Specifications

**Manufacturer**: Maxim Integrated (Analog Devices)

**Model**: DS3231M

**Communication**: I2C (address 0x68)

**Supply Voltage**: 2.3-5.5V

**Battery Backup**: CR2032 coin cell

**Accuracy**: ±5ppm (±2 minutes per year)

**Temperature Range**: -40 to +85°C

### Features

**TCXO**: Temperature-compensated crystal oscillator

**Alarm Functions**: Two programmable alarms

**32kHz Output**: Optional square wave output

**Aging Offset**: Software-adjustable for long-term accuracy

### Library

**Name**: Custom implementation (DS3231M.h/cpp)

**Based on**: Maxim DS3231 datasheet

### Initialization

```cpp
bool rtc_inicializar() {
    if (!rtc.begin()) {
        DEBUG_ERROR("RTC not found");
        while (1);  // Halt (RTC is critical)
    }

    if (rtc.lostPower()) {
        DEBUG_WARN("RTC lost power, setting time");
        // Set time from compile time or user input
        rtc.adjust(DateTime(F(__DATE__), F(__TIME__)));
    }

    DEBUG_INFO("RTC initialized");
    return true;
}
```

### Setting Time

**From Compile Time** (during upload):

```cpp
rtc.adjust(DateTime(F(__DATE__), F(__TIME__)));
```

**Manual** (specific date/time):

```cpp
// Set to October 16, 2025, 14:30:00
rtc.adjust(DateTime(2025, 10, 16, 14, 30, 0));
```

### Reading Time

```cpp
DateTime now = rtc.getRTCTime();

Serial.print(now.year());
Serial.print("/");
Serial.print(now.month());
Serial.print("/");
Serial.print(now.day());
Serial.print(" ");
Serial.print(now.hour());
Serial.print(":");
Serial.print(now.minute());
Serial.print(":");
Serial.println(now.second());
```

### Alarm Configuration

```cpp
void rtc_alarma_inicializar() {
    // Set alarm to trigger every 10 minutes
    // (triggered when minute == 0, 10, 20, 30, 40, 50)

    rtc.disableAlarm(1);
    rtc.disableAlarm(2);
    rtc.clearAlarm(1);
    rtc.clearAlarm(2);

    // Configure alarm 1 to match minutes
    rtc.setAlarm(ALM1_MATCH_MINUTES, 0, 0, 0, 1);

    DEBUG_INFO("RTC alarms configured");
}
```

### Battery Backup

**Purpose**: Maintains time during power loss

**Battery**: CR2032 (3V, ~200mAh)

**Expected Lifetime**: 5-10 years (depending on temperature)

**Replacement**: When time is lost after power cycles

### Temperature Reading

The DS3231M includes a temperature sensor for crystal compensation:

```cpp
float rtc_temp = rtc.getTemperature();
Serial.print("RTC Temperature: ");
Serial.print(rtc_temp);
Serial.println("°C");
```

**Accuracy**: ±3°C (not calibrated for ambient measurement)

**Update Rate**: Every 64 seconds

**Use Case**: Monitoring RTC temperature, not air temperature

### Troubleshooting

**RTC Not Detected**:

1. Check I2C connections
2. Verify power supply
3. Ensure address is 0x68

**Time Lost After Power Cycle**:

1. Replace CR2032 backup battery
2. Check battery holder connections
3. Re-set time after battery replacement

**Incorrect Time**:

1. Verify timezone configuration in `Datetime_helper.h`
2. Check if daylight saving time adjustment is needed
3. Manually set time if necessary

## I2C Bus Troubleshooting

### I2C Scanner

Use this sketch to detect all I2C devices:

```cpp
#include <Wire.h>

void setup() {
  Serial.begin(115200);
  Wire.begin();

  Serial.println("I2C Scanner");
  Serial.println("Scanning...");

  byte count = 0;
  for (byte i = 1; i < 127; i++) {
    Wire.beginTransmission(i);
    byte error = Wire.endTransmission();

    if (error == 0) {
      Serial.print("Device found at 0x");
      if (i < 16) Serial.print("0");
      Serial.println(i, HEX);
      count++;
    }
  }

  Serial.print("Found ");
  Serial.print(count);
  Serial.println(" device(s)");
}

void loop() {}
```

**Expected Output**:

```text
Device found at 0x15  (T6793)
Device found at 0x68  (DS3231M)
Device found at 0x69  (SEN54)
Found 3 device(s)
```

### Common I2C Issues

**No Devices Found**:

- Check SDA/SCL connections
- Verify pull-up resistors (4.7kΩ)
- Ensure 5V power to sensors

**Communication Errors**:

- Reduce I2C bus speed
- Shorten wire lengths
- Check for electromagnetic interference

**Intermittent Failures**:

- Verify power supply stability
- Check for loose connections
- Monitor for voltage drops during transmission

## Related Documentation

- [Program Flow](program-flow.md) - How sensors are read in main loop
- [Architecture](architecture.md) - System architecture overview
- [Data Transmission](data-transmission.md) - How sensor data is transmitted
- [Firmware Configuration](../user-guide/firmware-configuration.md) - Device configuration

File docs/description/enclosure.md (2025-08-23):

---
title: Enclosure design
subtitle: 
description: 
status: 
icon: material/developer-board
---

<!-- LICENSE INFORMATION
Copyright (C) 2025 ATARI Research Lab
Permission is granted to copy, distribute and/or modify this document
under the terms of the GNU Free Documentation License, Version 1.3
or any later version published by the Free Software Foundation;
with no Invariant Sections, no Front-Cover Texts, and no Back-Cover Texts.
A copy of the license is included in the section entitled "GNU
Free Documentation License". 
-->

For the enclosure design, SOLIDWORKS 2020 was used for modeling and Creality Print for preparing the print file, with the printing being carried out on a Sigmax R19 3D printer. To arrange the elements inside the enclosure, the specifications of the components were reviewed, with the SEN54 sensor presenting the most restrictions. Among others, it is necessary to place both heat sources (battery) and data transmission sources (antenna) as far as possible from the sensors. In addition, the different necessary gap requirements for the sensor to function correctly in relation to air intake and output, as well as the side vents, were taken into account. This enclosure is formed by a perforated pattern to allow air to pass through the device.

To make a more compact enclosure, an internal two-level structure was arranged, whose separation is given by the manufactured PCB for the prototype, which is screwed to the base of the enclosure. As shown in the figure, in the area below the PCB, separated by 2 mm, the device's battery is placed along with the NB-IoT transmission module, both being held to prevent movement and possible failure. Above the PCB are both sensors, in addition to the microcontroller board, charge manager, and RTC, all connected to the PCB that acts as a base. The placement of all of them has been following the specific indications mentioned above, to avoid failures during the operation of the sensors, as well as data transmission or the functioning of the entire device.

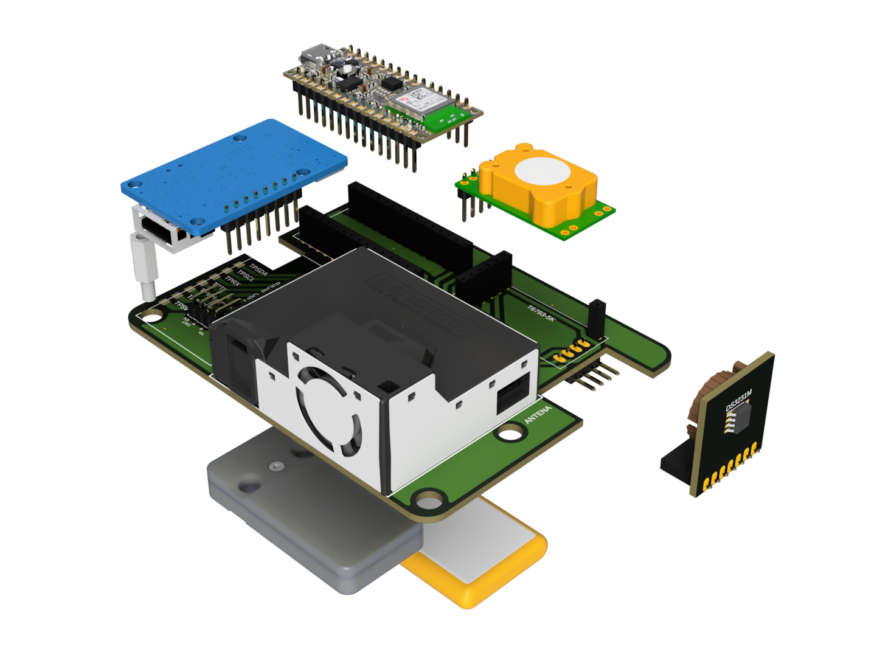
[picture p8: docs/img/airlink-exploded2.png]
CICERONE Airlink explosionated 3D model with the case showing the distribution of the modules


In this way, the organization of the different components allows it to be in a more reduced space and, therefore, be a manageable device for the user for its use and placement on a surface. It should be noted that on the back of the device, there is the outlet for the power supply, in addition to a switch for turning on the device.

[airlink-exploded2]: ../img/airlink-exploded2.png

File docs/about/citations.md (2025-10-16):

---
title: Citations
subtitle:
description:
status:
icon: material/file-link
---

<!-- LICENSE INFORMATION
Copyright (C) 2025 ATARI Research Lab
Permission is granted to copy, distribute and/or modify this document
under the terms of the GNU Free Documentation License, Version 1.3
or any later version published by the Free Software Foundation;
with no Invariant Sections, no Front-Cover Texts, and no Back-Cover Texts.
A copy of the license is included in the section entitled "GNU
Free Documentation License".
-->

<!-- markdownlint-disable MD046 -->

<!-- --8<-- [start:cite] -->
Please consider citing our papers in your publications if the project helps your research.

=== "APA"

    --8<-- "./about/citation/apa.txt"

=== "BibTex"

    --8<-- "./about/citation/bibtex.bib"

<!-- --8<-- [end:cite] -->

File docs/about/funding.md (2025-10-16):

---
title: Funding
subtitle:
description:
status:
icon: material/cash-multiple
---

<!-- LICENSE INFORMATION
Copyright (C) 2025 ATARI Research Lab
Permission is granted to copy, distribute and/or modify this document
under the terms of the GNU Free Documentation License, Version 1.3
or any later version published by the Free Software Foundation;
with no Invariant Sections, no Front-Cover Texts, and no Back-Cover Texts.
A copy of the license is included in the section entitled "GNU
Free Documentation License".
-->

## Funding

This results are part of the project PID2021-126810OB-I00 granted by MCIN/AEI/
10.13039/501100011033/; by "ERDF A way of making Europe".

micin-uefeder-aei logo

## Acknowledgments

This work was supported results are part of the project PID2021-126810OB-I00 granted by MCIN/AEI/
10.13039/501100011033/; by "ERDF A way of making Europe"; by the "Instituto de Investigación e
Innovación en Ciencias Biomédicas de Cádiz (IN-CO07)"; and by the "Consejería de Economía,
Innovación, Ciencia y Empleo de la Junta de Andalucía" (TIC-212).

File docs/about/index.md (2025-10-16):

---
title: About
subtitle:
description:
status:
icon: material/information-variant-box-outline
---

<!-- LICENSE INFORMATION
Copyright (C) 2025 ATARI Research Lab
Permission is granted to copy, distribute and/or modify this document
under the terms of the GNU Free Documentation License, Version 1.3
or any later version published by the Free Software Foundation;
with no Invariant Sections, no Front-Cover Texts, and no Back-Cover Texts.
A copy of the license is included in the section entitled "GNU
Free Documentation License".
-->

<p align="center">
  CICERONE Project Logo CICERONE Logo
</p>

Artificial intelligence, smart sensing, and new physiological and environmental predictors for
enhancing COPD management (aka CICERONE).

COPD (chronic obstructive disease) is a progressive lung disease affecting millions of people
worldwide, compromising their quality of life and presenting significant challenges for traditional
healthcare.

Traditional approaches to patient monitoring often fall short of providing timely and comprehensive
care. The lack of specificity of existing clinical decision support systems for predicting
exacerbations that have been evaluated in recent clinical trials leads to frequent clinically
unnecessary alerts, overuse of healthcare resources, inadequate management of COPD symptoms, and
avoidable levels of stress and anxiety for patients and caregivers. As mentioned, the need for
further research to identify symptoms and measures that enable early deterioration detection in
patients with COPD is unquestionable. Evidence points to a comprehensive plan assisted by predictive
technology that can meet this need.

Recognizing the pressing need for innovative solutions, our project **CICERONE** integrates
cutting-edge sensor technology and artificial intelligence algorithms. By leveraging these tools,
we aim to provide continuous and personalized monitoring to COPD patients, empowering them to manage
their condition proactively from their homes.

Through this portal, we invite patients, healthcare professionals, and the general public to explore
the advancements, discoveries, and outcomes of our project. Together, we are paving the way towards
a future where telemedicine revolutionizes how we approach COPD care, improving the quality of life
for those living with this chronic disease.

The research proposed in **CICERONE**, coordinated by the Research Group in Bioengineering,
Automation, and Robotics of the University of Cadiz,  will move the management of COPD from a
generic to a personalized approach, through the research of physiological parameters for the
prediction of COPD exacerbations, and the generation of personalized predictive models that offer
a compromise between clinical understanding and the goodness of statistical fit.

## 🗨️ Contact information

- **Email**: Send us your inquiries or support requests at grupoibt "at" uca.es
- **Website**: Visit the CICERONE project oficial website for more information [Cicerone](https://cicerone.uca.es)
- **Grupo ATARI UCA**: Know more of the research group in our official website [Grupo ATARI UCA](https://tic212.uca.es)

<p align="center">
  ATARIUCA Research lab logo ATARIUCA Logo
</p>

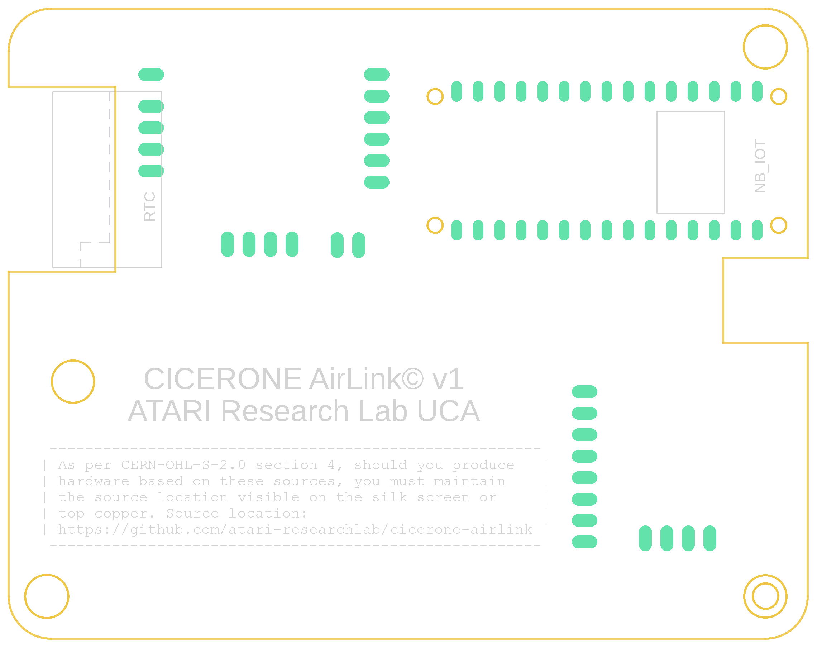
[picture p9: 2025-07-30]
hardware/PCB/ImageFiles/Bottom.png

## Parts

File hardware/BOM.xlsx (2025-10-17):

Qty | Device | Detailed Description | Vendor | Vendor Reference | Price
1 | LIPO_RIDER | LiPo Rider Plus de SeedStudio | Mouser Electronics | 713-106990290 | 4.59 € | Female Headers
1 | NB_IOT | M5Stack U111 | Mouser Electronics | 170-U111 | 21.30 € | Quantity | Type | Device
1 | RTC | DFRobot RTC DS3231M | Mouser Electronics | 426-DFR0641 | 6.43 € | 1 | 1x8 | LIPO_RIDER
1 | NANO33_BLE | Arduino Nano 33 BLE Sense Rev2 | Arduino Store | ABX00069 | 30.57 € | 1 | 1x6 | T6793-5K
1 | T6793-5K | Amphenol Telaire T6793-5K | Mouser Electronics | 527-T6793-5K | 25.84 € | 1 | 1x4 | SEN5X
1 | SEN5X | Sensirion SEN54 | Mouser Electronics | 403-SEN54-SDN-T | 19.36 € | 1 | 1x1 | T6793-5K
1 | Rocker Switch | On-Off external switch | Amazon |  | 0.50 € | 2 | 1x15 (opt) | NANO33_BLE
1 | PG7 Cable Gland |  | Amazon |  | 0.65 €
1 | STANDOFF | Hex Male-Female M3x12 standoff. Support for the LiPo Rider | Mouser Electronics | 761-M2107-3005-B | 0.97 € | Male Headers
1 | AC-DC micro USB adapter | AC-DC micro USB adapter Fuente de alimentación 5V@1A | Mouser Electronics | 552-AA10E-050A(M)-R | 6.00 € | Quantity | Type | Device
1 | LiPo Battery | Lipo Battery 900mAh | BricoGeek | 603048 | 5.95 € | 2 | 1x4 90deg | RTC, USB_SWITCH1
1 | Antenna | NB-IoT antenna | Mouser Electronics | 538-146185-0300 | 2.98 € | 1 | 1x2 (opt) | IMEAS1
1 | PCB |  | Eurocircuits |  | 5.00 €
1 | Case | ABS 3D printed enclosure | Impresoras3D | Filamento 1,75mm y 1kg | 1.77 €
1 | 3D printing | 3D printing energy consumption |  |  | 0.80 €
1 | IMEAS1 | Header for current measurement. Need to cut the trace between de pads in de top face of the PCB |  |  | 0.00 €
1 | USB_SWITCH1 | Header to connect the AC-DC adapter and the switch

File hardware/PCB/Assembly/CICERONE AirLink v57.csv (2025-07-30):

Part | Value | Device | Package | Description | POPULARITY | TP_SIGNAL_NAME | VALUE
CURR_MEAS | I? | CURR-MEAS | PIN2X1 |  |  |  | I?
LIPO_RIDER | LIPO-RIDER | LIPO-RIDER | LIPO-RIDER-STAND
NANO33_BLE | NANO33_BLEPIN | NANO33_BLEPIN | NANO_BLE33_PIN | Arduino Nano V3.0
NB_IOT | GROVE-UARTSMD | GROVE-UARTSMD | GROVE_SMD
POWER_SWITCH | USB_SWITCH | USB_SWITCH | USB-SWITCH
RTC | MODULO_RTC | RTC-DS3231MMOD-90 | DS3231M-MOD-90
SEN5X | I2C-HEADER | I2C-HEADER | I2C-HEADER
T6793-5K | T6793 | T6793 | T6793
TP5V | PTR1TP20SQ | PTR1TP20SQ | TP20SQ | TEST PIN | 0
TPBAT | PTR1TP20SQ | PTR1TP20SQ | TP20SQ | TEST PIN | 0
TPRX | PTR1TP20SQ | PTR1TP20SQ | TP20SQ | TEST PIN | 0
TPSCL | PTR1TP20SQ | PTR1TP20SQ | TP20SQ | TEST PIN | 0
TPSDA | PTR1TP20SQ | PTR1TP20SQ | TP20SQ | TEST PIN | 0
TPTX | PTR1TP20SQ | PTR1TP20SQ | TP20SQ | TEST PIN | 0
TPVIN | PTR1TP20SQ | PTR1TP20SQ | TP20SQ | TEST PIN | 0

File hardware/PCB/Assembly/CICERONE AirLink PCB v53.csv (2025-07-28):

Part | Value | Device | Package | Description | POPULARITY | TP_SIGNAL_NAME | VALUE
IMEAS1 | I? | PIN2X1IMEAS | PIN2X1 |  |  |  | I?
LIPO_RIDER | LIPO-RIDER | LIPO-RIDER | LIPO-RIDER
NANO33_BLE | NANO33_BLEPIN | NANO33_BLEPIN | NANO_BLE33_PIN | Arduino Nano V3.0
NB_IOT | MODULO_NB_IOT | MODULO_NB_IOT | MOD_NBI_OT
RTC | MODULO_RTC | MODULO_RTC | MOD_RTC
SEN5X | SENSOR_VOCS | SENSOR_VOCS | SEN_VOCS_CONECTOR
T6793-5K | SENSOR_CO2 | SENSOR_CO2 | SEN_CO2_T6793
TP5V | PTR1TP20SQ | PTR1TP20SQ | TP20SQ | TEST PIN | 0
TPBAT | PTR1TP20SQ | PTR1TP20SQ | TP20SQ | TEST PIN | 0
TPRX | PTR1TP20SQ | PTR1TP20SQ | TP20SQ | TEST PIN | 0
TPSCL | PTR1TP20SQ | PTR1TP20SQ | TP20SQ | TEST PIN | 0
TPSDA | PTR1TP20SQ | PTR1TP20SQ | TP20SQ | TEST PIN | 0
TPTX | PTR1TP20SQ | PTR1TP20SQ | TP20SQ | TEST PIN | 0
TPVIN | PTR1TP20SQ | PTR1TP20SQ | TP20SQ | TEST PIN | 0
USB_SWITCH1 | USB_SWITCH | USB_SWITCH | USB_SWITCH

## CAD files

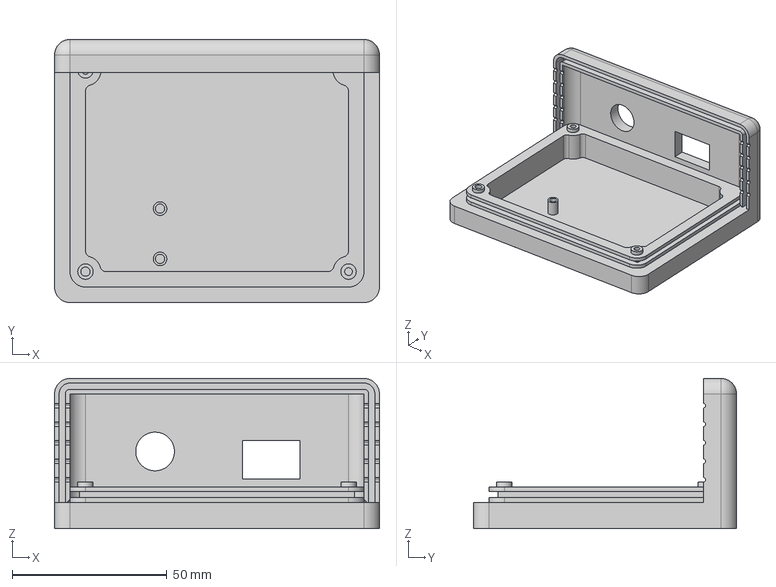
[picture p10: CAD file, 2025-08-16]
hardware/Case/Airlink Case - Bottom.step
105.0 x 85.0 x 48.5 mm

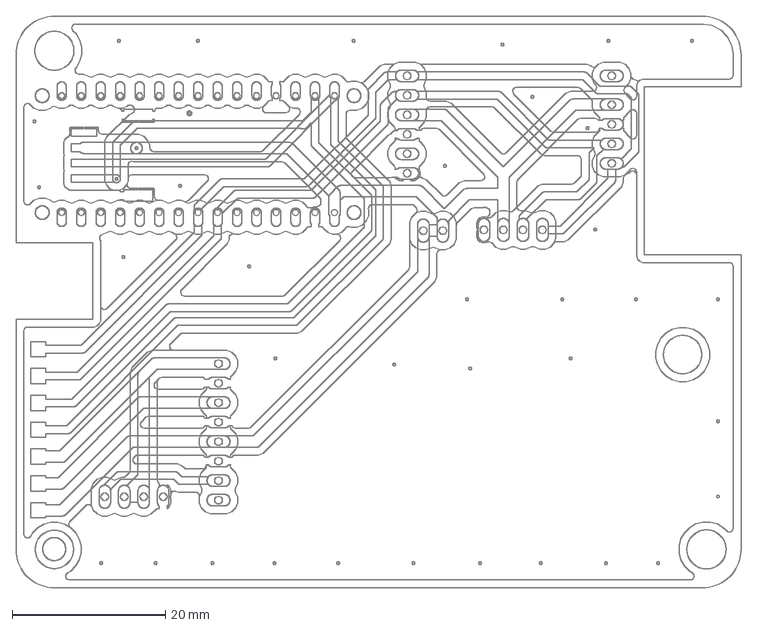
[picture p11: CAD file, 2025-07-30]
hardware/PCB/DrawingFiles/CICERONE AirLink v57.dxf
94.5 x 74.5 mm

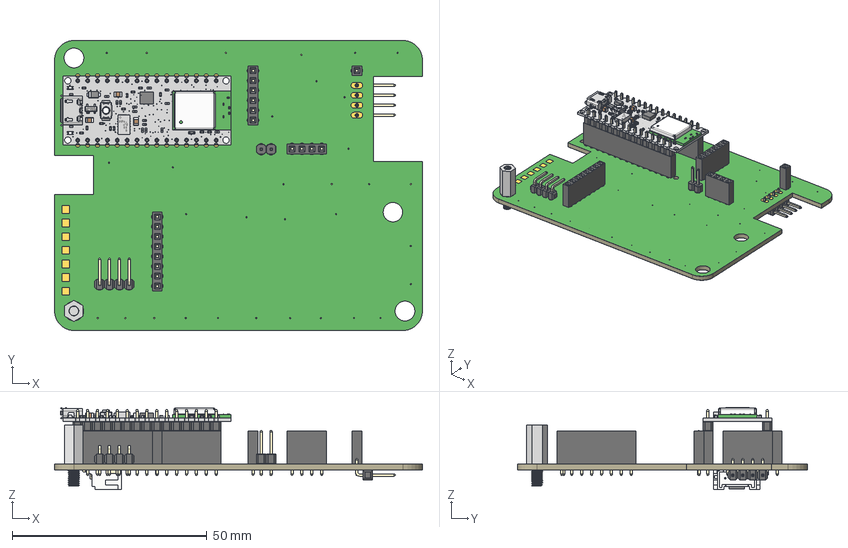
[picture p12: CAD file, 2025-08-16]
hardware/PCB/Eagle files/CICERONE_AirLink.step
94.5 x 74.5 x 21.1 mm
Board
1-copper
16-copper
1-soldermask
16-soldermask
Female header x15 v1 x 2
LSM9DS1TR_LGA-24_3X3P5X1_STM v1
ZX62-AB-5PA (1)
IoT_HSMG-C190 LED v1 x 2
IoT_MPM3610 Step-Down Module v1
User Library-arduino_nano_reset core
User Library-arduino_nano_reset shell
RC0402FR-071KL RC0402N_YAG v1 x 27
BLM18EG101TN1D v1
C0805C472KDRACTU v1 x 3
PMEG6020AELRX v1
IoT_PRTR5V0U2X Protection Diode v1
NINA-B306-00B-00--3DModel-STEP-56544 v1
Board (1)
Pin x 30
Piece x 30
Grove Connector SMD 90 v3
STANDOFF_HEX_MALE-FEMALE_M3_10mm v4
Pin (1) x 2
Piece (1) x 2
Female header 1x1 v1

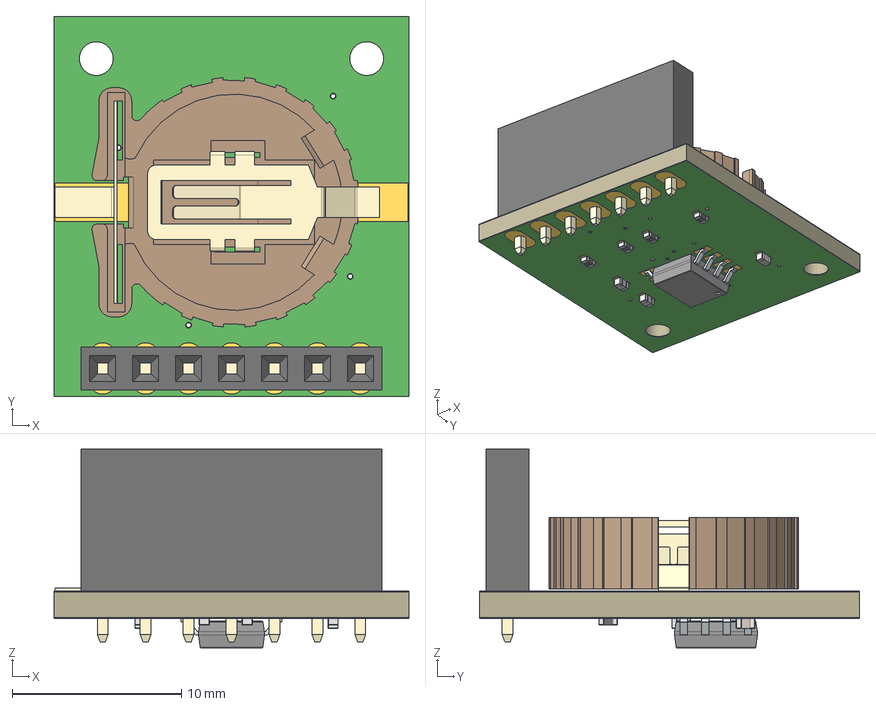
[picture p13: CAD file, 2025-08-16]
hardware/PCB/Eagle files/External Components/DFROBOT DS3231M.step
21.0 x 22.5 x 11.8 mm
Board
1-copper
16-copper
1-soldermask
16-soldermask
9216695.f3d x 3
Holder
Rear Contact
Lower Contact
PinsArrayLR
5576505.f3d x 4

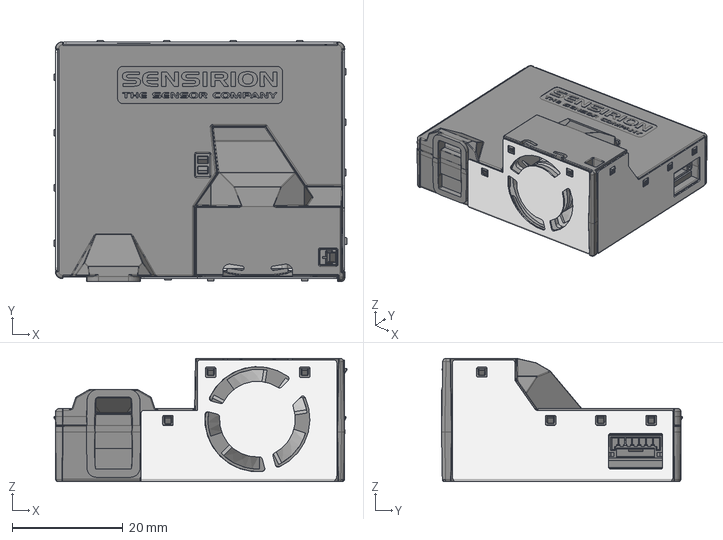
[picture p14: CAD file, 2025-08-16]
hardware/PCB/Fusion360/External Components/Sensirion SEN5x.step
52.9 x 43.6 x 22.3 mm

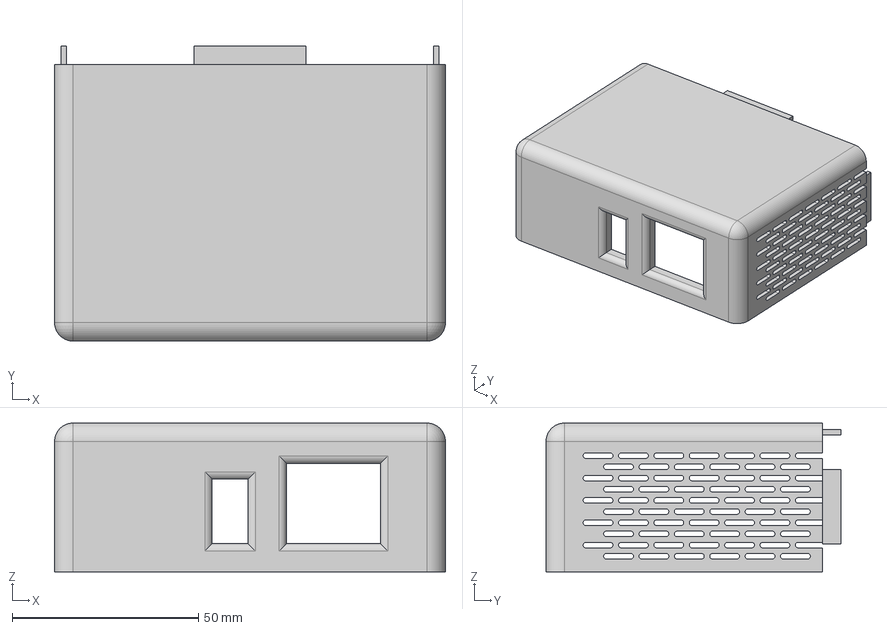
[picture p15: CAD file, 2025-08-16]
hardware/Case/Airlink Case - Top.step
105.0 x 79.3 x 40.0 mm

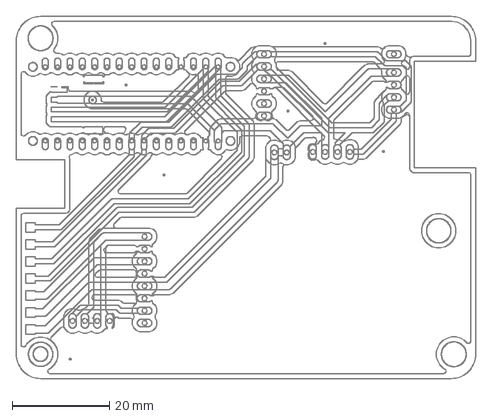
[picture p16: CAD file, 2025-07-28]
hardware/PCB/DrawingFiles/CICERONE AirLink PCB v53.dxf
94.5 x 74.5 mm

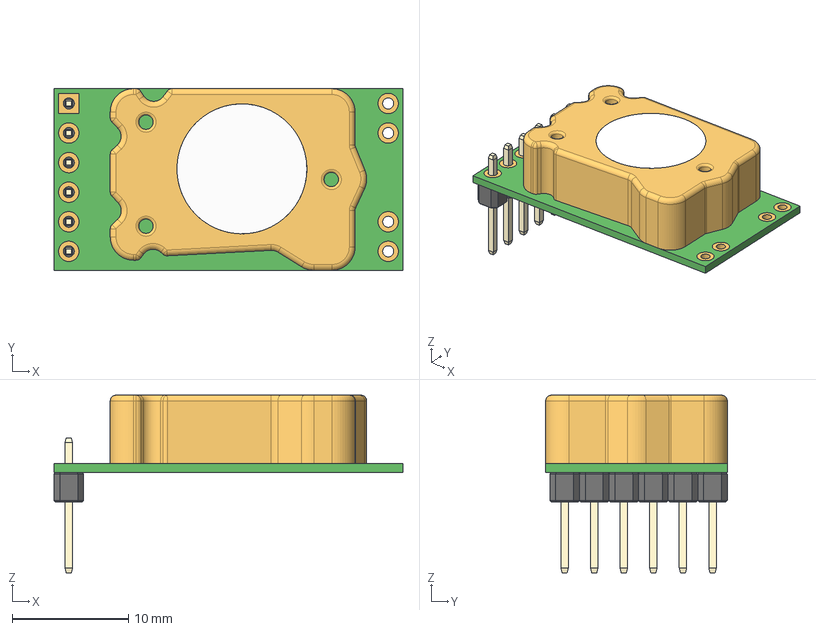
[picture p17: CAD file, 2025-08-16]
hardware/PCB/Eagle files/External Components/T6793.step
30.0 x 15.6 x 15.3 mm
Pin x 6
Piece x 6

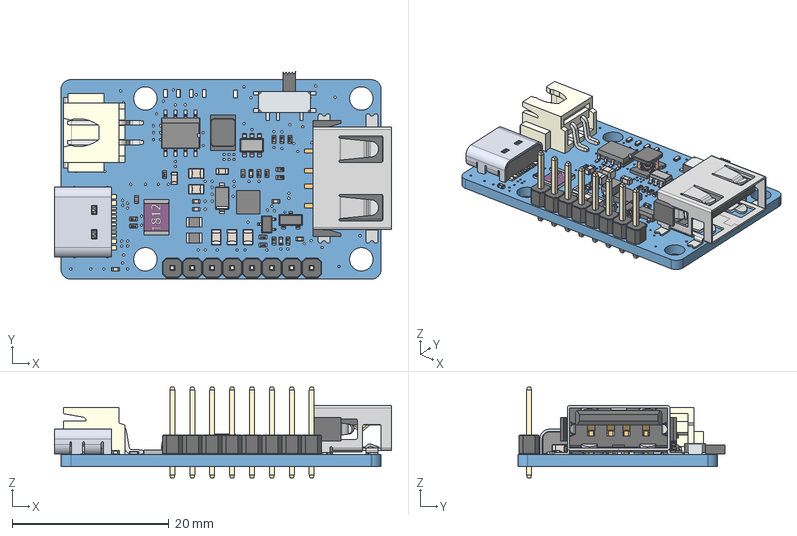
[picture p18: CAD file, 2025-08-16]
hardware/PCB/Eagle files/External Components/Lipo Rider Plus.step
43.0 x 26.5 x 11.6 mm
Board
HW2-SMD-2.0-90D
USB2.0-TYPE-C
Pin1
Pin2
CeramicBody
Pin1 (1)
Pin2 (1)
CeramicBody (1)
Pin1 (2)
Pin2 (2)
CeramicBody (2)
Pin1 (3)
Pin2 (3)
CeramicBody (3)
Coating
Light
Cathode Mark
Anode Pin
Cathode Pin
Base
Light (1)
Cathode Mark (1)
Anode Pin (1)
Cathode Pin (1)
Base (1)
Light (2)
Cathode Mark (2)
Anode Pin (2)
Cathode Pin (2)
Base (2)
Light (3)
Cathode Mark (3)
Anode Pin (3)
Cathode Pin (3)
Base (3)
Light (4)
Cathode Mark (4)
Anode Pin (4)
Cathode Pin (4)
Base (4)
Pin1Body
Pin2Body
CeramicBody (4)
CoatingBody
Text1Body
Text2Body
Text3Body
Text4Body
Pin1Body (1)
Pin2Body (1)
CeramicBody (5)
CoatingBody (1)
Text1Body (1)
Text2Body (1)
Text3Body (1)
Text4Body (1)
Pin1Body (2)
Pin2Body (2)
CeramicBody (6)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

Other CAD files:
hardware/Case/Airlink Case - Bottom.f3d
hardware/Case/Airlink Case - Top.f3d
hardware/PCB/Fusion360/CICERONE AirLink.f3d
hardware/PCB/Fusion360/CICERONE AirLink.f3z
hardware/PCB/Fusion360/External Components/DFROBOT DS3231M.f3d
hardware/PCB/Fusion360/External Components/DFROBOT DS3231M.f3z
hardware/PCB/Fusion360/External Components/Lipo Rider Plus.f3d
hardware/PCB/Fusion360/External Components/T6793.f3d

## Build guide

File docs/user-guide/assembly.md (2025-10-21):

---
title: Assembly instructions
subtitle:
description:
status:
icon: material/soldering-iron
---

<!-- LICENSE INFORMATION
Copyright (C) 2025 ATARI Research Lab
Permission is granted to copy, distribute and/or modify this document
under the terms of the GNU Free Documentation License, Version 1.3
or any later version published by the Free Software Foundation;
with no Invariant Sections, no Front-Cover Texts, and no Back-Cover Texts.
A copy of the license is included in the section entitled "GNU
Free Documentation License".
-->

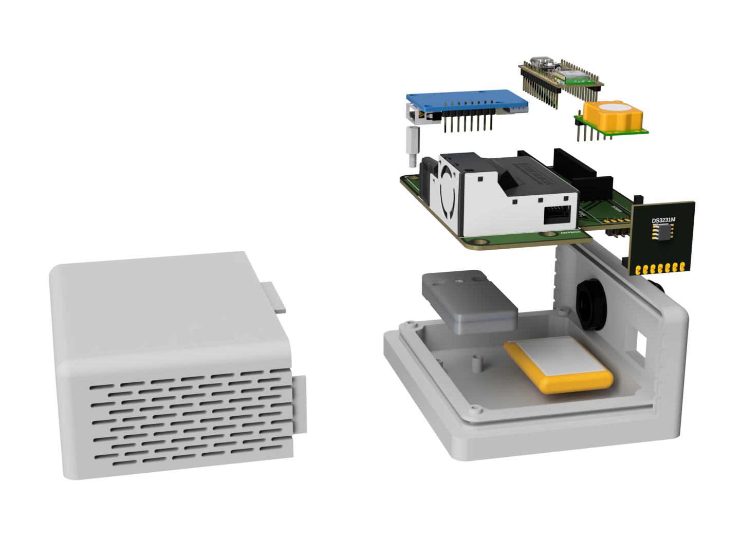
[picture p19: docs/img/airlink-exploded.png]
CICERONE Airlink explosionated 3D model with the case showing the distribution of the modules inside the enclosure


Steps 1, 2, 3 and 4: Mount the components on the top face of the PCB, as shown.

Assembly Diagram 1 - Components connected to the PCB

Step 5: Place the pins of the SEN54 sensor into the set of 4 female pins located next to the sensor
from step 2.

Step 6: Place the cable gland in the hole, as shown. To do this, you will have to open the inner
nut beforehand.

Assembly Diagram 2 - Placing the cable gland, securing the battery and communications module

Steps 7 and 8: Secure the LiPo battery and the M5Stack communications module to the base of the
casing. To secure the battery, you can use double-sided adhesive tape again.

Step 9: Place the PCB onto the casing's mounting surface that has 3 holes, as observed in the next
figure. During this process, you will need to take the following steps into account:

* First, connect the communications module's cable to the surface connector located on the underside
  of the PCB.
* Check that the battery cable passes through the rectangular cutout on the left side of the PCB.
* Check that the antenna cable passes through the space where the RTC is placed.

Assembly Diagram 3 - Placing the PCB in the enclosure

Step 10: Assemble the two cables from the AC-DC Converter (charger) and the two cables from the
switch into a 4-pin female header connector, as shown.

Connector for the dc power and switch under the lipo-rider

Step 11: Place the standoff screw (bottom-left image) and 3 screws into the remaining holes to fix
the PCB to the casing.

Assembly Diagram 4 - Fixing the PCB to the enclosure

Step 12: Place the 4-pin connector from step 9 onto the set of 4 available male pins.

Step 13: Place the "LiPo Rider Plus" charge management module onto the set of 8 female pins. You
must take into account that the charge management module has a switch on the bottom that should be
left in the OFF state.

Step 14: Adhere the antenna to the inner face of the top part of the casing.

Connector for the dc power and switch under the lipo-rider

Step 15: Slide the top part of the casing along the guides provided for this purpose. Be careful
not to pinch the antenna cable when closing the casing.

Connector for the dc power and switch under the lipo-rider

[airlink-exploded]: ../img/airlink-exploded.png
[assembly1]: ../img/assembly-1.png
[assembly2]: ../img/assembly-2.png
[assembly3]: ../img/assembly-3.png
[assembly4]: ../img/assembly-4.png
[connector]: ../img/connector-charger-switch.jpg
[antenna]: ../img/antenna.jpg
[final-device]: ../img/airlink-final-device.png

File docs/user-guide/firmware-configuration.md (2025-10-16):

---
title: Firmware configuration
subtitle:
description:
status:
icon: material/tune
---

<!-- LICENSE INFORMATION
Copyright (C) 2025 ATARI Research Lab
Permission is granted to copy, distribute and/or modify this document
under the terms of the GNU Free Documentation License, Version 1.3
or any later version published by the Free Software Foundation;
with no Invariant Sections, no Front-Cover Texts, and no Back-Cover Texts.
A copy of the license is included in the section entitled "GNU
Free Documentation License".
-->

## Overview

The `Configuracion.h` file centralizes all configurable parameters for the CICERONE AirLink
firmware. This allows you to customize the device behavior without modifying the core source code.
All configuration options are defined using preprocessor directives (`#define`).

!!! info "File Location"
    The configuration file is located at: `firmware/Configuracion.h`

## Configuration Parameters

### Device Identification

#### `ID_USUARIO`

Defines a unique identifier for this device. This ID is included in all data transmissions to
identify the source device on the server.

**Default value:**

```cpp
#define ID_USUARIO "AIRLINK_01"
```

**Usage:**

- Change this value to assign a unique name to each device in your deployment
- Use alphanumeric characters and underscores
- Keep it short but descriptive (e.g., "AIRLINK_ROOM_301", "AIRLINK_LAB_A")

**Example:**

```cpp
#define ID_USUARIO "AIRLINK_BEDROOM_02"
```

### NB-IoT Module Control

#### `HABILITAR_NBIOT`

Enables or disables the NB-IoT communication module. When disabled, the device will still collect
sensor data but will not transmit it to the server.

**Default value:**

```cpp
#define HABILITAR_NBIOT 1
```

**Options:**

- `1` - Enable NB-IoT transmission (default)
- `0` - Disable NB-IoT transmission

**Usage:**

- Set to `1` when you want to enable remote telemonitoring
- Set to `0` for testing, development, or standalone data logging without connectivity
- Disabling NB-IoT saves power and reduces operational costs

**Example (disabled):**

```cpp
#define HABILITAR_NBIOT 0
```

!!! tip "Power Saving"
    Disabling NB-IoT can significantly extend battery life if you only need local data logging via
    the serial monitor.

### Server Configuration

These parameters define where the device sends its data via HTTP POST requests.

#### `SERVIDOR_IP`

The server's IP address or domain name where data will be transmitted.

**Default value:**

```cpp
#define SERVIDOR_IP "http://direccion.servidor.com"
```

**Usage:**

- Replace with your actual server URL or IP address
- Include the protocol prefix (`http://` or `https://`)
- Do not include trailing slashes

**Examples:**

```cpp
#define SERVIDOR_IP "http://192.168.1.100"
#define SERVIDOR_IP "http://iot.mycompany.com"
#define SERVIDOR_IP "https://api.airquality.example.org"
```

#### `SERVIDOR_PUERTO`

The server port number for the HTTP connection.

**Default value:**

```cpp
#define SERVIDOR_PUERTO "64340"
```

**Usage:**

- Must be provided as a string (enclosed in quotes)
- Common values: `"80"` (HTTP), `"443"` (HTTPS), or custom ports
- Coordinate with your server administrator

**Examples:**

```cpp
#define SERVIDOR_PUERTO "80"      // Standard HTTP port
#define SERVIDOR_PUERTO "443"     // Standard HTTPS port
#define SERVIDOR_PUERTO "8080"    // Alternative HTTP port
```

#### `SERVIDOR_API`

The API endpoint path on the server that receives the data.

**Default value:**

```cpp
#define SERVIDOR_API "/aqindoor"
```

**Usage:**

- Define the relative path to your API endpoint
- Always start with a forward slash (`/`)
- Must match the endpoint configured on your server

**Examples:**

```cpp
#define SERVIDOR_API "/api/v1/airquality"
#define SERVIDOR_API "/data/sensors"
#define SERVIDOR_API "/receive"
```

!!! example "Complete Server URL"
    The device constructs the full URL by combining these parameters:
    <!-- markdownlint-disable MD046 -->
    ``` SERVIDOR_IP:SERVIDOR_PUERTO/SERVIDOR_API ```

    For example: `http://iot.mycompany.com:64340/aqindoor`

### Network Provider Configuration

#### `APN_NBIOT`

Access Point Name (APN) for the mobile network operator's data service.

**Default value:**

```cpp
#define APN_NBIOT "iot.1nce.net"
```

**Usage:**

- Contact your IoT SIM card provider for the correct APN
- Some providers work without an APN (use empty string `""`)
- This is crucial for establishing data connectivity

**Common APN Examples:**

| Provider | APN Value |
|---|---|
| 1NCE | `"iot.1nce.net"` |
| ThingMobile | `"TM"` |
| Vodafone IoT | `"nb.iотgprs"` |
| No APN required | `""` |

**Example configurations:**

```cpp
#define APN_NBIOT "iot.1nce.net"  // 1NCE
#define APN_NBIOT "TM"            // ThingMobile
#define APN_NBIOT ""              // No APN required
```

!!! warning "Important"
    Using an incorrect APN will prevent the device from connecting to the internet. Always verify
    with your SIM card provider.

## Configuration Workflow

### Step-by-Step Guide

1. **Open the configuration file**

   Navigate to `firmware/Configuracion.h` in your code editor

2. **Set device identification**

   Assign a unique `ID_USUARIO` for each device

3. **Configure server details**

   Enter your server's IP address, port, and API endpoint

4. **Set network APN**

   Enter the APN provided by your IoT SIM card operator

5. **Enable/disable NB-IoT**

   Set `HABILITAR_NBIOT` based on your requirements

6. **Compile and upload**

   Build and flash the firmware to your device using Arduino CLI

### Example Configuration

Here's a complete example configuration for a typical deployment:

```cpp
#ifndef CONFIGURACION_H
#define CONFIGURACION_H

// Device identification
#define ID_USUARIO "AIRLINK_HOSPITAL_ROOM_305"

// Enable NB-IoT transmission
#define HABILITAR_NBIOT 1

// Server configuration
#define SERVIDOR_IP "http://iot.hospital.org"
#define SERVIDOR_PUERTO "443"
#define SERVIDOR_API "/api/v2/airquality/data"

// Network provider APN
#define APN_NBIOT "iot.1nce.net"

#endif  // CONFIGURACION_H
```

## Compilation Notes

!!! info "Preprocessor Directives"
    All configuration options use `#define` preprocessor directives. Changes take effect at compile
    time, so you must recompile and upload the firmware after modifying `Configuracion.h`.

### Conditional Compilation

The `HABILITAR_NBIOT` flag uses conditional compilation. When set to `0`, all NB-IoT related code
is excluded from the compiled binary, resulting in:

- Smaller program size
- Reduced memory usage
- Lower power consumption
- Faster startup time

This is implemented throughout the codebase using preprocessor conditionals:

```cpp
#if HABILITAR_NBIOT
    // NB-IoT code is included
    nbiot_enviar();
#endif
```

## Troubleshooting

### Connection Issues

If the device cannot connect to the server:

1. **Verify APN**: Ensure `APN_NBIOT` matches your provider's specification
2. **Check server URL**: Confirm `SERVIDOR_IP` is reachable from the internet
3. **Validate port**: Ensure `SERVIDOR_PUERTO` is not blocked by firewalls
4. **Test API endpoint**: Verify `SERVIDOR_API` accepts POST requests

### Debug Mode

For detailed troubleshooting information, enable debug output in `Debug.h`:

```cpp
#define DEBUG_LEVEL 3           // Set to 3 for verbose output
#define DEBUG_NBIOT 3           // Enable NB-IoT debug messages
```

Monitor the serial output (115200 baud) to see connection attempts and error messages.

## Related Documentation

- [Debug Configuration](debug-configuration.md) - Configure debug output levels
- [API Reference](../firmware/api/files.md) - Complete firmware documentation
- [Hardware Assembly](assembly.md) - Physical device setup

## See Also

- **`Debug.h`** - Configure debug output and testing modes
- **`Datetime_helper.h`** - Timezone and time synchronization settings
- **Firmware API Documentation** - Complete code reference with Doxygen

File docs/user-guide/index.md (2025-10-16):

---
title: User Guide
subtitle:
description: Complete guide for building, configuring, and deploying CICERONE AirLink devices
status:
icon: fontawesome/solid/user-gear
---

<!-- LICENSE INFORMATION
Copyright (C) 2025 ATARI Research Lab
Permission is granted to copy, distribute and/or modify this document
under the terms of the GNU Free Documentation License, Version 1.3
or any later version published by the Free Software Foundation;
with no Invariant Sections, no Front-Cover Texts, and no Back-Cover Texts.
A copy of the license is included in the section entitled "GNU
Free Documentation License".
-->

<!-- markdownlint-disable MD033 MD030 -->

## Welcome

This user guide provides comprehensive instructions for assembling, configuring, and deploying
CICERONE AirLink indoor air quality monitoring devices. Whether you're building your first device
or customizing firmware parameters, you'll find detailed step-by-step guidance here.

## Getting Started

The deployment process consists of three main stages:

<div class="grid cards" markdown>

-   :material-soldering-iron: **[Hardware Assembly](assembly.md)**

    ---

    Learn how to assemble the PCB, connect sensors, and integrate all components into the custom
    enclosure. Includes detailed diagrams and step-by-step instructions.

    [:octicons-arrow-right-24: Assembly Instructions](assembly.md)

-   :material-tune: **[Firmware Configuration](firmware-configuration.md)**

    ---

    Configure device parameters through `Configuracion.h`: set device ID, NB-IoT credentials,
    server endpoints, and enable/disable modules.

    [:octicons-arrow-right-24: Configuration Guide](firmware-configuration.md)

-   :material-bug: **[Debug Configuration](debug-configuration.md)**

    ---

    Set up the debug system through `Debug.h`: control logging verbosity, enable per-module
    debugging, and optimize for production deployment.

    [:octicons-arrow-right-24: Debug System](debug-configuration.md)

</div>

## Quick Reference

!!! tip "Typical Workflow"
    1. **Build the hardware** following the [assembly instructions](assembly.md)
    2. **Configure the firmware** by editing [`Configuracion.h`](firmware-configuration.md) with
    your device ID and network settings
    3. **Set debug level** in [`Debug.h`](debug-configuration.md) (use `DEBUG_LEVEL 3` for testing,
    `0` for production)
    4. **Compile and upload** the firmware to your Arduino Nano 33 BLE Sense Rev2
    5. **Validate operation** using the serial monitor with debug output enabled

## Additional Resources

- **[Firmware Architecture](../firmware/index.md)**: Understand the internal architecture, timer
  system, and data flow
- **[Hardware Description](../description/electronics.md)**: Detailed PCB design and electronic components
- **[Enclosure Design](../description/enclosure.md)**: 3D model specifications and mechanical integration

---

!!! question "Need Help?"
    If you encounter issues during assembly or configuration, check the
    [firmware architecture documentation](../firmware/index.md) for troubleshooting guidance.

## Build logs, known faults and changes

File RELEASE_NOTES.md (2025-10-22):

# Release v2.0.0 - First Public Release

## 🎉 Description

First stable release of **CICERONE AirLink**, an indoor air quality telemonitoring device with
NB-IoT for respiratory disease research.

## ✨ Main Features

### Hardware

- **Custom 2-layer PCB** (v57) with schematics and Gerber files
- **Integrated sensors**: SEN54 (PM/VOC), T6793-5K (CO₂), DS3231M (RTC)
- **Communication**: SIM7020G NB-IoT module for data transmission
- **Power**: 900mAh LiPo battery with 5-hour autonomy
- **Enclosure**: 3D model for printing (SOLIDWORKS/Fusion360)

### Firmware

- **Modular architecture** with non-blocking timers (5s and 10min)
- **Automatic transmission** of averages every 10 minutes via HTTP POST
- **Multi-level debug system** configurable per module
- **Conditional compilation** for memory optimization
- **Compatible** with Arduino Nano 33 BLE Sense Rev2

### Documentation

- **Complete website** with MkDocs Material + Doxygen
- **User guides**: assembly, firmware configuration, debugging
- **Technical documentation**: architecture, program flow, sensor interfaces
- **Auto-generated API** from source code comments
- **Dual language**: English (primary) and Spanish (firmware)

## 🔧 Contents

```text
├── firmware/          # Arduino code (English)
├── firmware_es/       # Arduino code (Spanish)
├── hardware/          # PCB, schematics and manufacturing files
│   ├── PCB/          # KiCad/Eagle, Gerber, assembly
│   └── Case/         # 3D models (STEP, Fusion360)
├── docs/             # MkDocs documentation
└── .github/          # CI/CD workflows
```

## 📦 Dependencies

**Firmware:**

- Arduino Core: `arduino:mbed_nano@4.4.1`
- ArduinoJson: `7.4.2`
- Sensirion I2C SEN5X: `0.3.0`
- Sensirion Core: `0.7.1`

**Documentation:**

- Python 3.8+
- mkdocs-material
- mkdoxy
- mkdocs-awesome-nav

## 🚀 Quick Start

### Compile Firmware

```bash
cd firmware
arduino-cli compile --profile nano33ble
arduino-cli upload --profile nano33ble -p COM3
```

### View Documentation

```bash
pip install mkdocs-material mkdoxy mkdocs-awesome-nav
mkdocs serve
```

Visit: <https://atari-researchlab.github.io/cicerone-airlink/>

## 🐛 Fixes in this Release

- ✅ Git LFS support in deployment workflow (assembly images)
- ✅ Fixed image paths in documentation
- ✅ Configuration of markdownlint and VSCode
- ✅ Correct exclusion of auto-generated files in mkdocs

## 📄 Licenses

- **Firmware**: GPL-3.0-or-later
- **Hardware**: CERN-OHL-S-2.0 (Open Hardware)
- **Documentation**: GFDL-1.3-or-later

## 🙏 Funding

Grant **PID2021-126810OB-I00** funded by MCIN/AEI and EU FEDER Funds.

<!-- markdownlint-disable MD041 MD013 -->

<p align="center">
  Grant <strong><em>PID2021-126810OB-I00</em></strong> funded by:<br />
  Funded by Ministerio de Ciencia, Innovación y Universidades, European Union and Agencia Estatal de Investigacion<br />
</p>

---

**Project status**: Active | **Documentation**: <https://atari-researchlab.github.io/cicerone-airlink/>

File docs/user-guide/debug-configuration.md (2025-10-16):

---
title: Debug Configuration
subtitle:
description:
status:
icon: material/bug
---

<!-- LICENSE INFORMATION
Copyright (C) 2025 ATARI Research Lab
Permission is granted to copy, distribute and/or modify this document
under the terms of the GNU Free Documentation License, Version 1.3
or any later version published by the Free Software Foundation;
with no Invariant Sections, no Front-Cover Texts, and no Back-Cover Texts.
A copy of the license is included in the section entitled "GNU
Free Documentation License".
-->

## Overview

The `Debug.h` file provides a comprehensive debug message management system for the CICERONE
AirLink firmware. It implements a multi-level logging framework that allows you to control the
verbosity of debug output on a per-module basis through the serial monitor.

!!! info "File Location"
    The debug configuration file is located at: `firmware/Debug.h`

!!! tip "Memory Optimization"
    When `DEBUG_LEVEL` is set to 0, all debug macros compile to empty statements. The compiler
    optimizes them out completely, saving both flash memory and RAM while improving performance.

## Debug System Architecture

### Message Format

Debug messages follow a standardized format that includes three key components:

```text
[LEVEL][TIMESTAMP][MODULE] Message content
```

**Example output:**

```text
[ERROR][1543][RTC] Unable to establish communication with RTC
[INFO][5012][SEN5X] Sensor initialized successfully
[VERBOSE][10234][NBIOT] AT+CGATT response: +CGATT: 1
```

### Components Breakdown

1. **LEVEL**: Message severity (`ERROR`, `WARN`, `INFO`, `VERBO`)
2. **TIMESTAMP**: Milliseconds since device startup (from `millis()`)
3. **MODULE**: Source module identifier (defined by `DEBUG_TAG`)
4. **Message**: Formatted debug message content

## Debug Levels

The debug system implements a hierarchical logging system with four severity levels:

| Level | Value | Name | Description | Use Case |
|---|---|---|---|---|
| **0** | 0 | **Disabled** | No debug output | Production deployment |
| **1** | 1 | **ERROR** | Critical errors only | Minimal debugging |
| **2** | 2 | **WARN** | Errors + warnings | Standard operation |
| **3** | 3 | **INFO** | General program flow | Recommended for development |
| **4** | 4 | **VERBOSE** | Detailed information | Deep debugging (e.g., sensor readings every 5s) |

!!! note "Hierarchical System"
    Setting a debug level automatically enables all lower levels. For example, `DEBUG_LEVEL = 3`
    (INFO) will also display WARN and ERROR messages.

## Configuration Parameters

### Global Debug Level

#### `DEBUG_LEVEL`

Controls the global verbosity threshold for all debug messages.

**Default value:**

```cpp
#define DEBUG_LEVEL 3
```

**Options:**

- `0` - Disable all debug output (production mode)
- `1` - Show only ERROR messages
- `2` - Show ERROR + WARN messages
- `3` - Show ERROR + WARN + INFO messages (recommended for development)
- `4` - Show all messages including VERBOSE details

**Usage:**

Set this value based on your debugging needs. For production deployments, always set to `0` to save
memory and improve performance.

**Examples:**

```cpp
#define DEBUG_LEVEL 0    // Production: no debug output
#define DEBUG_LEVEL 3    // Development: general debugging
#define DEBUG_LEVEL 4    // Deep debugging: all details
```

### Per-Module Debug Levels

The debug system allows fine-grained control over each firmware module independently. This is useful
when troubleshooting a specific component without being overwhelmed by messages from other modules.

#### `DEBUG_ALARMA`

Controls debug output from the timing and data acquisition loop (`Alarma.cpp`).

**Default value:**

```cpp
#define DEBUG_ALARMA 2
```

**Messages include:**

- 5-second alarm triggers
- 10-minute alarm triggers
- Data accumulation events
- Averaging calculations

#### `DEBUG_SEN5X`

Controls debug output from the SEN54 particulate matter and VOC sensor (`SEN5X_API.cpp`).

**Default value:**

```cpp
#define DEBUG_SEN5X 2
```

**Messages include:**

- Sensor initialization status
- I2C communication errors
- Sensor readings (at VERBOSE level)
- Data quality warnings

#### `DEBUG_T6793`

Controls debug output from the Telaire T6793-5K CO₂ sensor (`T6793_API.cpp`).

**Default value:**

```cpp
#define DEBUG_T6793 2
```

**Messages include:**

- Sensor initialization status
- I2C communication errors
- CO₂ readings (at VERBOSE level)
- Calibration status

#### `DEBUG_DS3231M`

Controls debug output from the DS3231M Real-Time Clock (`DS3231M.cpp`).

**Default value:**

```cpp
#define DEBUG_DS3231M 2
```

**Messages include:**

- RTC initialization status
- Time synchronization events
- I2C communication errors
- Temperature readings from RTC

#### `DEBUG_NBIOT`

Controls debug output from the SIM7020G NB-IoT module (`Transmision_NBIOT.cpp`).

**Default value:**

```cpp
#define DEBUG_NBIOT 2
```

**Messages include:**

- Module initialization sequence
- Network registration status
- AT command exchanges (at VERBOSE level)
- HTTP POST request/response
- Connection errors

!!! example "Per-Module Configuration Example"
    To debug only the NB-IoT module while keeping other modules quiet:
    <!-- markdownlint-disable MD046 -->
    ```cpp
    #define DEBUG_LEVEL 4        // Enable all message types
    #define DEBUG_ALARMA 0       // Disable alarm messages
    #define DEBUG_SEN5X 0        // Disable SEN5X messages
    #define DEBUG_T6793 0        // Disable T6793 messages
    #define DEBUG_DS3231M 0      // Disable RTC messages
    #define DEBUG_NBIOT 4        // Show verbose NB-IoT messages
    ```

## Testing Configuration

### `TEST_MINUTAL`

Enables per-minute data transmission instead of the standard 10-minute interval.

**Default value:**

```cpp
#define TEST_MINUTAL 1
```

**Options:**

- `1` - Enable 1-minute transmission interval (testing mode)
- `0` - Use standard 10-minute interval (production mode)

**Usage:**

This is extremely useful for:

- Testing data transmission without waiting 10 minutes
- Debugging server communication
- Validating sensor readings quickly
- Verifying JSON packet format

!!! warning "Testing Only"
    Always disable `TEST_MINUTAL` (set to `0`) for production deployments. Sending data every minute
    significantly increases:
    <!-- markdownlint-disable MD046 -->
    - Power consumption
    - Data costs
    - Server load
    - SIM card data usage

## Debug Macros

The debug system provides four macros that work like `printf()` with automatic formatting and module
tagging.

### Available Macros

#### `DEBUG_ERROR(format, ...)`

Prints critical error messages. Always use for fatal errors that prevent normal operation.

**Example:**

```cpp
DEBUG_ERROR("Unable to establish communication with RTC");
DEBUG_ERROR("Sensor initialization failed with error code: %d", error_code);
```

**Output:**

```text
[ERROR][1543][RTC] Unable to establish communication with RTC
[ERROR][1544][SEN5X] Sensor initialization failed with error code: -1
```

#### `DEBUG_WARN(format, ...)`

Prints warning messages for non-critical issues that should be investigated.

**Example:**

```cpp
DEBUG_WARN("Temperature reading out of expected range: %.2f°C", temp);
DEBUG_WARN("Network registration took longer than expected");
```

**Output:**

```text
[WARN][5234][T6793] Temperature reading out of expected range: 45.23°C
[WARN][12456][NBIOT] Network registration took longer than expected
```

#### `DEBUG_INFO(format, ...)`

Prints informational messages about normal program flow and state changes.

**Example:**

```cpp
DEBUG_INFO("Sensor initialized successfully");
DEBUG_INFO("Connected to network, signal strength: %d", rssi);
```

**Output:**

```text
[INFO][3421][SEN5X] Sensor initialized successfully
[INFO][45678][NBIOT] Connected to network, signal strength: -72
```

#### `DEBUG_VERBOSE(format, ...)`

Prints detailed diagnostic information, typically sensor readings or low-level communication details.

**Example:**

```cpp
DEBUG_VERBOSE("PM2.5: %.2f, PM10: %.2f, VOC: %d", pm25, pm10, voc);
DEBUG_VERBOSE("AT command: %s, Response: %s", cmd, response);
```

**Output:**

```text
[VERBO][10234][SEN5X] PM2.5: 12.34, PM10: 23.45, VOC: 156
[VERBO][10456][NBIOT] AT command: AT+CGATT?, Response: +CGATT: 1
```

## Module Identification with DEBUG_TAG

Each source file (`.cpp`) defines its own `DEBUG_TAG` macro to identify the source of debug
messages. This tag appears in the `[MODULE]` field of every debug message.

### How DEBUG_TAG Works

**At the beginning of each `.cpp` file, define:**

```cpp
#define DEBUG_TAG "MODULE_NAME"
```

**This tag is then automatically included in all debug messages from that file.**

### Standard DEBUG_TAG Definitions

| File | DEBUG_TAG | Description |
|---|---|---|
| `Alarma.cpp` | `"ALARMA"` | Timing and data acquisition loop |
| `SEN5X_API.cpp` | `"SEN5X"` | SEN54 sensor communication |
| `T6793_API.cpp` | `"T6793"` | CO₂ sensor communication |
| `DS3231M.cpp` | `"RTC"` | Real-time clock |
| `Transmision_NBIOT.cpp` | `"NBIOT"` | NB-IoT module |
| `firmware.ino` | `"MAIN"` | Main program setup |

### Example Implementation

**In `SEN5X_API.cpp`:**

```cpp
#include "Debug.h"

// Define module identifier for debug messages
#define DEBUG_TAG "SEN5X"

void sen5x_inicializar() {
  DEBUG_INFO("Initializing SEN54 sensor...");

  if (sen5x.begin(Wire) != 0) {
    DEBUG_ERROR("Failed to initialize sensor");
    return;
  }

  DEBUG_INFO("Sensor initialized successfully");
}

void sen5x_leer() {
  if (DEBUG_SEN5X >= 4) {
    DEBUG_VERBOSE("Reading sensor values...");
    DEBUG_VERBOSE("PM2.5: %.2f µg/m³", pm25);
    DEBUG_VERBOSE("PM10: %.2f µg/m³", pm10);
  }
}
```

**Output:**

```text
[INFO][2341][SEN5X] Initializing SEN54 sensor...
[INFO][2456][SEN5X] Sensor initialized successfully
[VERBO][5012][SEN5X] Reading sensor values...
[VERBO][5013][SEN5X] PM2.5: 12.34 µg/m³
[VERBO][5014][SEN5X] PM10: 23.45 µg/m³
```

!!! tip "Creating New Modules"
    When adding new source files to the firmware:
    <!-- markdownlint-disable MD046 -->
    1. Include `Debug.h` at the top
    2. Define a descriptive `DEBUG_TAG` (uppercase, max 8 characters recommended)
    3. Use debug macros throughout your code
    4. Optionally add a module-specific debug level in `Debug.h`

## Serial Monitor Configuration

To view debug messages, configure your serial monitor with the following settings:

**Baud rate:** `115200`

**Line ending:** `Newline` or `NL`

### Using Arduino IDE Serial Monitor

1. Open `Tools` → `Serial Monitor`
2. Set baud rate to `115200` in the bottom right
3. Set line ending to `Newline`

### Using Arduino CLI

```powershell
arduino-cli monitor -p COM3 -c baudrate=115200
```

## Practical Usage Examples

### Example 1: Production Configuration

Minimal debug output for deployed devices:

```cpp
#define TEST_MINUTAL 0      // 10-minute transmission
#define DEBUG_LEVEL 1       // Errors only
#define DEBUG_ALARMA 1
#define DEBUG_SEN5X 1
#define DEBUG_T6793 1
#define DEBUG_DS3231M 1
#define DEBUG_NBIOT 1
```

### Example 2: Development Configuration

Standard debugging during development:

```cpp
#define TEST_MINUTAL 1      // 1-minute transmission for testing
#define DEBUG_LEVEL 3       // Info level
#define DEBUG_ALARMA 3
#define DEBUG_SEN5X 3
#define DEBUG_T6793 3
#define DEBUG_DS3231M 2
#define DEBUG_NBIOT 3
```

### Example 3: Deep Sensor Debugging

Troubleshooting SEN54 sensor communication:

```cpp
#define TEST_MINUTAL 1      // Fast testing
#define DEBUG_LEVEL 4       // Verbose
#define DEBUG_ALARMA 2      // Reduce noise from timer
#define DEBUG_SEN5X 4       // Full sensor details
#define DEBUG_T6793 2
#define DEBUG_DS3231M 0     // Disable RTC messages
#define DEBUG_NBIOT 0       // Disable NB-IoT messages
```

### Example 4: NB-IoT Network Troubleshooting

Diagnosing connectivity issues:

```cpp
#define TEST_MINUTAL 1      // Test transmissions every minute
#define DEBUG_LEVEL 4       // Verbose
#define DEBUG_ALARMA 2
#define DEBUG_SEN5X 0       // Disable sensor messages
#define DEBUG_T6793 0
#define DEBUG_DS3231M 0
#define DEBUG_NBIOT 4       // Show all AT commands and responses
```

## Memory Considerations

### Flash Memory Impact

Debug strings are stored in flash memory. The approximate memory usage:

| Configuration | Flash Usage | Notes |
|---|---|---|
| `DEBUG_LEVEL = 0` | ~0 bytes | All debug code removed |
| `DEBUG_LEVEL = 1` | ~2-4 KB | Error messages only |
| `DEBUG_LEVEL = 3` | ~6-10 KB | Standard debugging |
| `DEBUG_LEVEL = 4` | ~10-15 KB | Full verbose output |

### RAM Impact

The debug system uses a static buffer for formatting messages:

**Buffer size:** `256 bytes` (defined by `DEBUG_PRINTF_BUFFER_SIZE`)

!!! info "Buffer Overflow Prevention"
    Keep debug messages under 256 characters. Longer messages will be truncated. If you need longer
    messages, increase `DEBUG_PRINTF_BUFFER_SIZE` in `Debug.h`.

## Troubleshooting

### No Debug Output

**Possible causes:**

1. **Serial monitor not connected**: Ensure USB cable is connected and correct COM port selected
2. **Wrong baud rate**: Must be set to `115200`
3. **DEBUG_LEVEL = 0**: Debug output is disabled
4. **Module debug level = 0**: Specific module output is disabled

**Solution:**

```cpp
#define DEBUG_LEVEL 3       // Enable INFO level
#define DEBUG_ALARMA 3      // Enable module output
```

### Garbled Output

**Possible causes:**

1. **Incorrect baud rate**: Check serial monitor settings
2. **Buffer overrun**: Messages too long for buffer

**Solution:**

- Set baud rate to `115200`
- Shorten debug messages or increase `DEBUG_PRINTF_BUFFER_SIZE`

### Missing Timestamps

**Possible cause:** Serial monitor capturing partial messages

**Solution:** Reset the device to see messages from startup

### Memory Warnings During Compilation

**Possible cause:** Debug level too high, consuming too much flash memory

**Solution:** Reduce `DEBUG_LEVEL` or disable verbose modules

## Compilation Notes

### Preprocessor Optimization

The debug system uses preprocessor conditionals to completely eliminate debug code when disabled:

```cpp
#if DEBUG_LEVEL == 0
#define DEBUG_ERROR(format, ...)
#define DEBUG_WARN(format, ...)
#define DEBUG_INFO(format, ...)
#define DEBUG_VERBOSE(format, ...)
#endif
```

When `DEBUG_LEVEL = 0`, the macros expand to nothing, and the compiler's optimization pass removes
all debug-related code, resulting in:

- Smaller binary size
- No runtime overhead
- No memory usage
- Faster execution

!!! success "Zero-Cost Abstraction"
    When debugging is disabled, there is literally **zero performance or memory cost** - it's as if
    the debug code never existed.

## Related Documentation

- [Firmware Configuration](firmware-configuration.md) - Configure device ID, server, and NB-IoT settings
- [API Reference](../firmware/api/files.md) - Complete firmware documentation
- [Hardware Assembly](assembly.md) - Physical device setup

## See Also

- **`Configuracion.h`** - Device configuration parameters
- **`Datetime_helper.h`** - Timezone configuration
- **Firmware API Documentation** - Complete code reference with Doxygen

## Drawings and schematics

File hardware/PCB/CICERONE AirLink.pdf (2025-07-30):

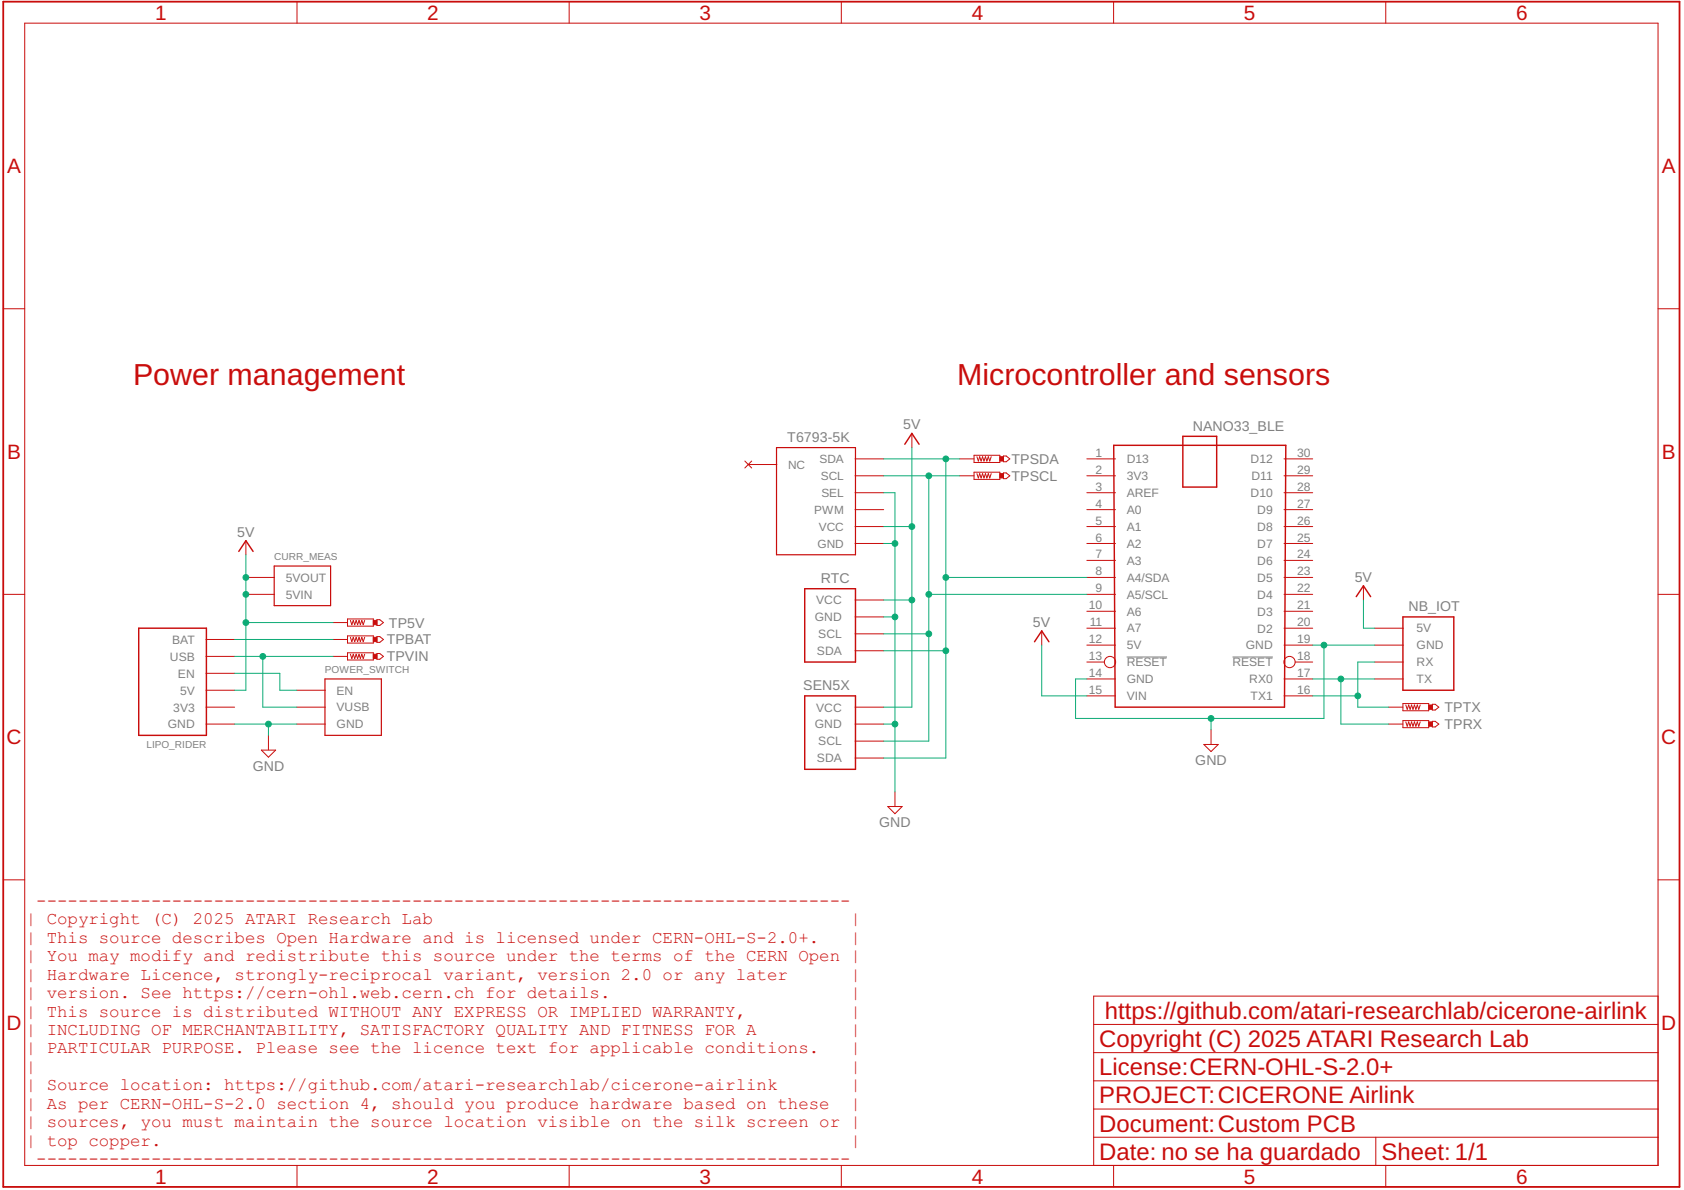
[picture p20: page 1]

You may modify and redistribute this source under the terms of the CERN Open
sources, you must maintain the source location visible on the silk screen or

https://github.com/atari-researchlab/cicerone-airlink
Copyright (C) 2025 ATARI Research Lab
License:
PROJECT:
Document:

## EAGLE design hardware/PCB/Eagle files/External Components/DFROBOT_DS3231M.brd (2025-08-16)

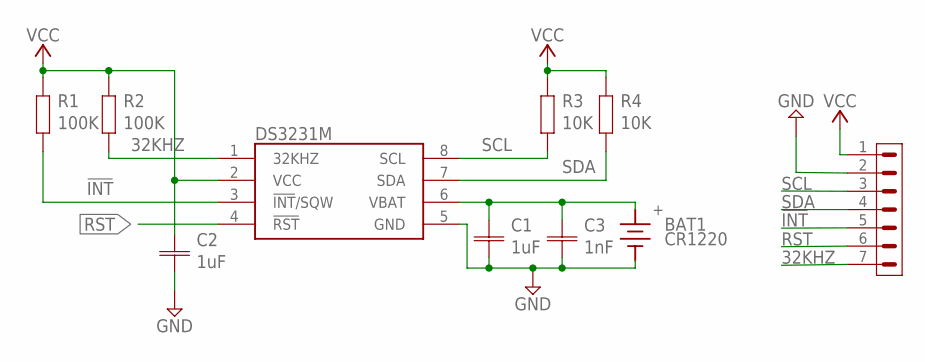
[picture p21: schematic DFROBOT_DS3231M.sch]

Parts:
BAT1: CR1220; S8411-45R
C1, C2: 1uF; CAPC1005X60
C3: 1nF; CAPC1005X60
DS3231M: DS3231MZ+; SOIC127P600X175-8N
JP1: PINHD-1X7; DS3231M_HEADER
R1, R2: 100K; RESC1005X40
R3, R4: 10K; RESC1005X40

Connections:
32KHZ: DS3231M.1 (32KHZ), JP1.7, R2.2
!INT: DS3231M.3 (!INT!/SQW), JP1.5, R1.2
GND: BAT1.1 (-), C1.2, C2.2, C3.2, DS3231M.5 (GND), JP1.2
RST: DS3231M.4 (!RST), JP1.6
SCL: DS3231M.8 (SCL), JP1.3, R3.2
SDA: DS3231M.7 (SDA), JP1.4, R4.2
VBAT: BAT1.2 (+), C1.1, C3.1, DS3231M.6 (VBAT)
VCC: C2.1, DS3231M.2 (VCC), JP1.1, R1.1, R2.1, R3.1, R4.1

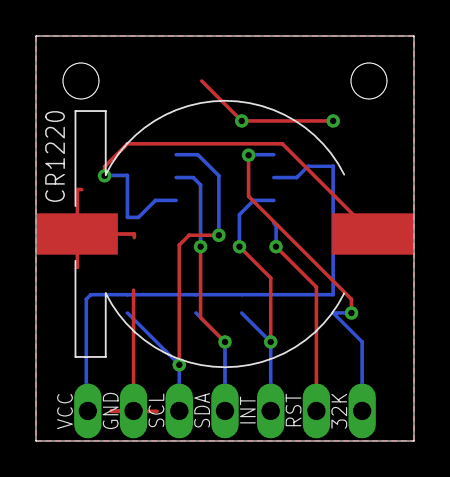
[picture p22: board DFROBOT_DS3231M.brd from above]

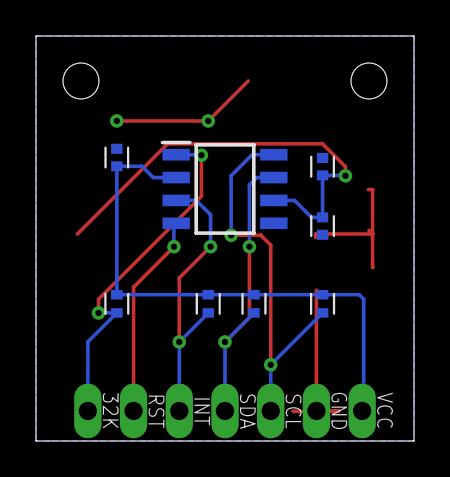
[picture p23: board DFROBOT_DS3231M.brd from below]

Board: 2 copper layers, 21.0 x 22.5 mm, 10 parts (8 on the bottom side), 8 nets.

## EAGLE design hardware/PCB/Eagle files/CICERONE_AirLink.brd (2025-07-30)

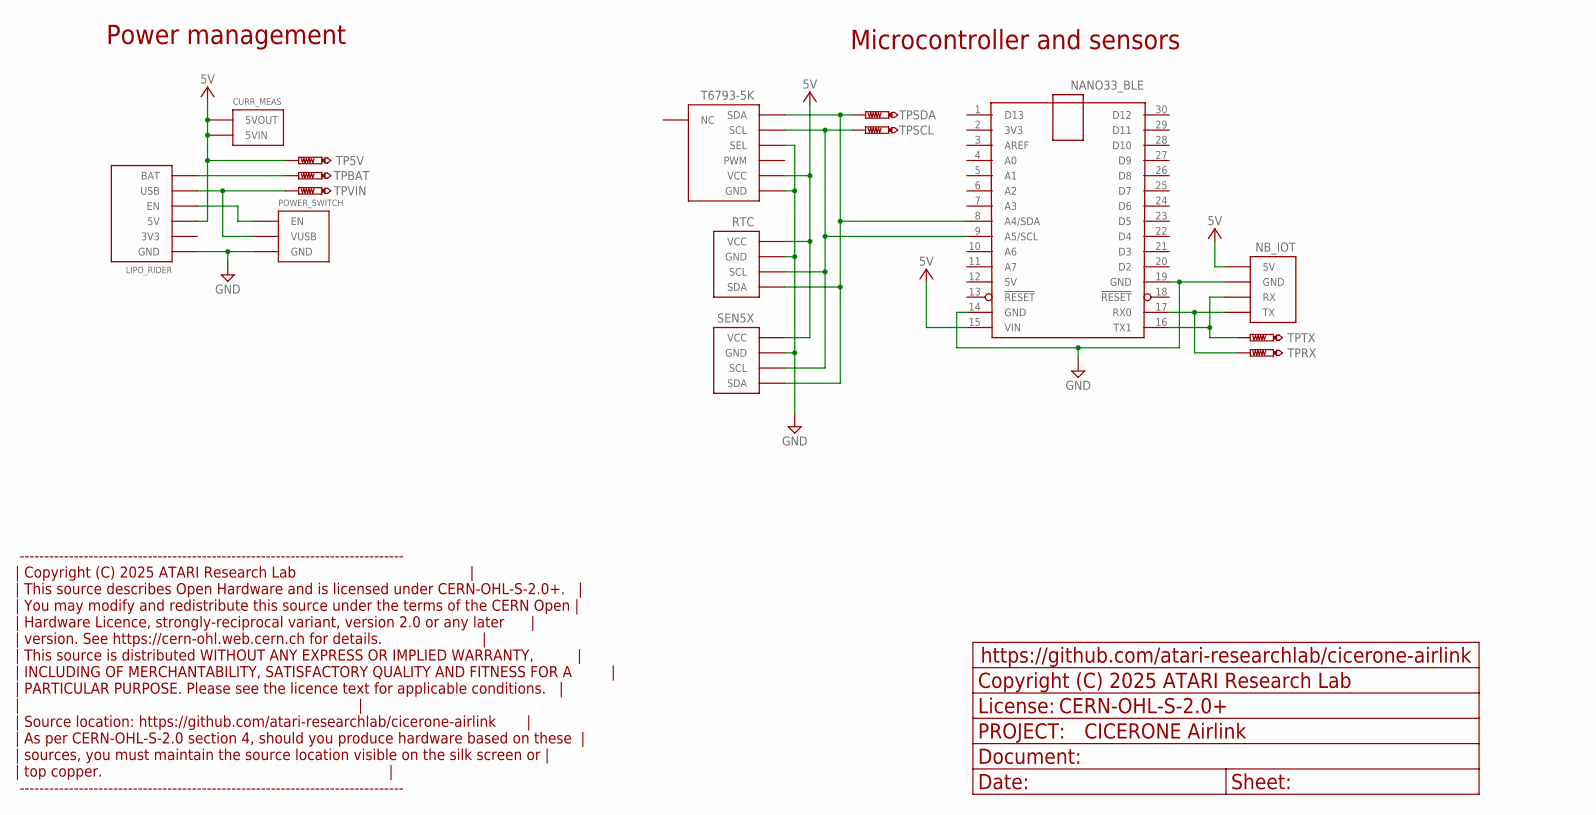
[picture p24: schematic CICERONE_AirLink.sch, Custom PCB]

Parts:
CURR_MEAS: I→; PIN2X1
LIPO_RIDER: LIPO-RIDER; LIPO-RIDER-STAND
NANO33_BLE: NANO33_BLEPIN; NANO_BLE33_PIN
NB_IOT: GROVE-UARTSMD; GROVE_SMD
POWER_SWITCH: USB_SWITCH; USB-SWITCH
RTC: MODULO_RTC; DS3231M-MOD-90
SEN5X: I2C-HEADER
T6793-5K: T6793
TP5V: PTR1TP20SQ; TP20SQ
TPBAT: PTR1TP20SQ; TP20SQ
TPRX: PTR1TP20SQ; TP20SQ
TPSCL: PTR1TP20SQ; TP20SQ
TPSDA: PTR1TP20SQ; TP20SQ
TPTX: PTR1TP20SQ; TP20SQ
TPVIN: PTR1TP20SQ; TP20SQ

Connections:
5V: CURR_MEAS.P$1 (5VOUT), CURR_MEAS.P$2 (5VIN), LIPO_RIDER.P$4 (5V), NANO33_BLE.15 (VIN), NB_IOT.ROJ (5V), RTC.P$1 (VCC), SEN5X.VCC, T6793-5K.P$3 (VCC), TP5V.TP
EN: LIPO_RIDER.P$2 (EN), POWER_SWITCH.P$4 (EN)
GND: LIPO_RIDER.P$3 (GND), LIPO_RIDER.P$5 (GND), LIPO_RIDER.P$7 (GND), NANO33_BLE.14 (GND), NANO33_BLE.19 (GND), NB_IOT.NEG (GND), NB_IOT.P$1 (GND), NB_IOT.P$2 (GND), POWER_SWITCH.P$1 (GND), RTC.P$2 (GND), SEN5X.GND, T6793-5K.P$4 (GND), T6793-5K.P$6 (SEL)
RX_ARDU: NANO33_BLE.17 (RX0), NB_IOT.BLA (TX), TPRX.TP
SCL: NANO33_BLE.9 (A5/SCL), RTC.P$3 (SCL), SEN5X.SCL, T6793-5K.P$2 (SCL), TPSCL.TP
SDA: NANO33_BLE.8 (A4/SDA), RTC.P$4 (SDA), SEN5X.SDA, T6793-5K.P$1 (SDA), TPSDA.TP
TX_ARDU: NANO33_BLE.16 (TX1), NB_IOT.AMA (RX), TPTX.TP
VBAT: LIPO_RIDER.P$6 (BAT), TPBAT.TP
VUSB: LIPO_RIDER.P$8 (USB), POWER_SWITCH.P$2 (VUSB), POWER_SWITCH.P$3 (VUSB), TPVIN.TP

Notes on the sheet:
Power management
Microcontroller and sensors
------------------------------------------------------------------------------ | Copyright (C) 2025 ATARI Research Lab | | This source describes Open Hardware and is licensed under CERN-OHL-S-2.0+. | | You may modify and redistribute this source under the terms of the CERN Open | | Hardware Licence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

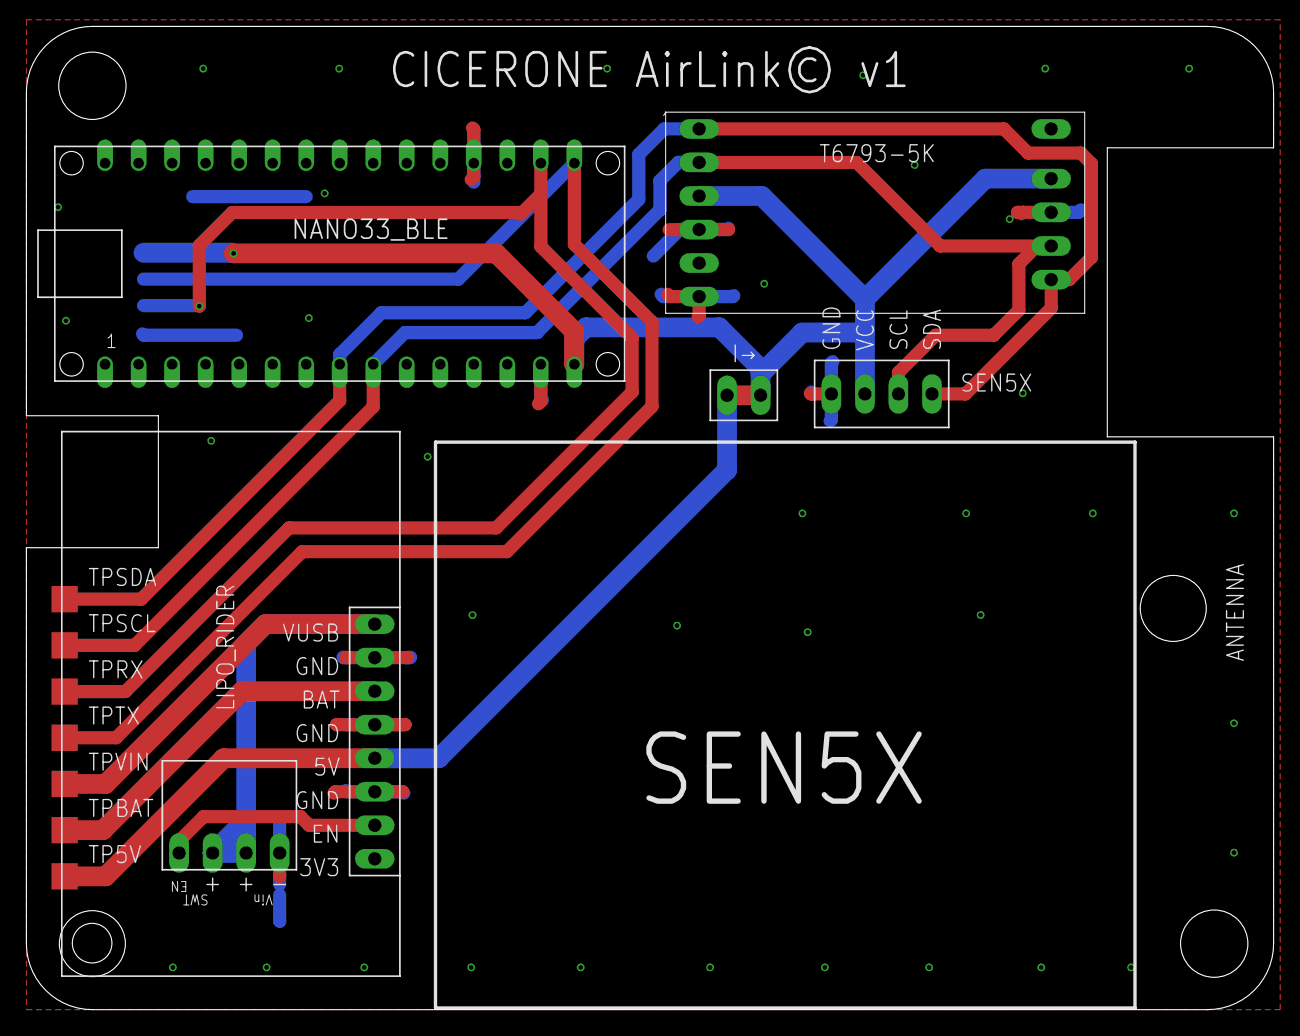
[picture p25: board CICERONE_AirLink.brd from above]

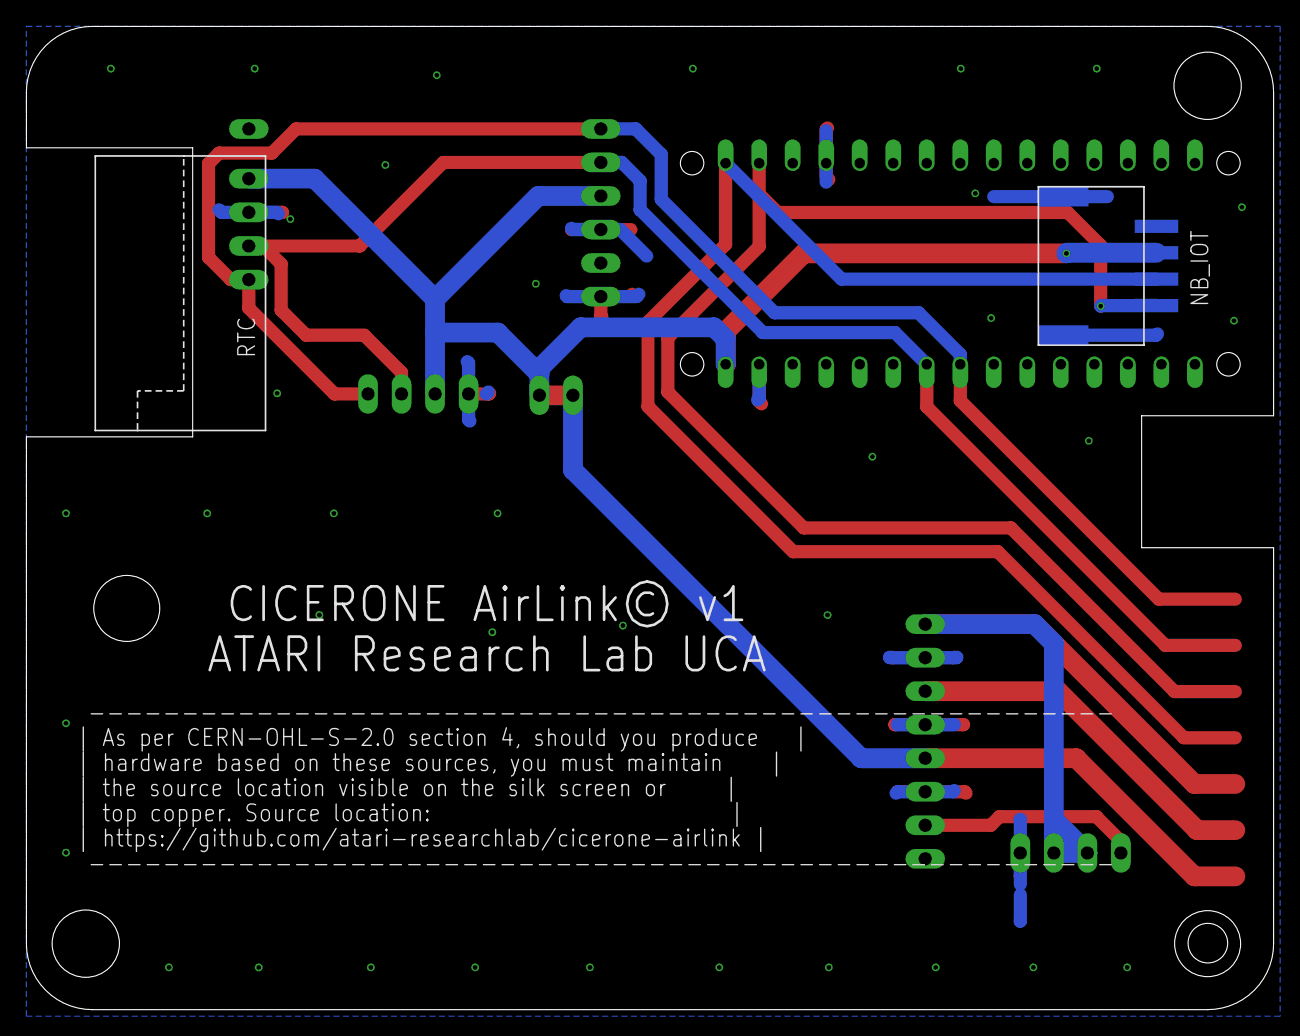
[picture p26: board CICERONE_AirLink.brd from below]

Board: 2 copper layers, 94.5 x 74.5 mm, 15 parts (2 on the bottom side), 9 nets.

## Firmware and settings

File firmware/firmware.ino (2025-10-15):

/***********************************************************************************************************************
 * @file        firmware.ino
 * @brief       Main code for an air quality monitoring system ("Airlink").
 * @details     This program integrates readings from various sensors and manages their operation
 * through non-blocking timers (millis). It includes optional modules
 * for data transmission via NB-IoT and for cough detection using Edge Impulse.
 *
 * @author      [ALD-DSL/ATARI_RESEARCH_LAB]
 * @date        [2024-07-22 / Last Modified]
 * @version     1.0-rc1
 *
 * @copyright   GNU General Public License version 3 or later
 * @warning     Server values and APN must be correctly configured to use the IoT module.
 * @see         Configuracion.h
 **********************************************************************************************************************/

#include "Configuracion.h"  // Central configuration file to enable/disable modules.
#include "Debug.h"          // Contains macros to control debug output via Serial.
#include "Alarma.h"         // Custom module for timer management (periodic alarms).
#include "SEN5X_API.h"      // API for handling the Sensirion SEN5X sensor.
#include "T6793_API.h"      // API for handling the T6793-5K CO2 sensor.

// --- Conditional module inclusion (controlled from Configuracion.h) ---
#if HABILITAR_NBIOT
#include "Transmision_NBIOT.h"  // Module for data transmission via Narrowband IoT.
#endif

#define DEBUG_TAG "MAIN"  //!< Tag when sending debug messages

/**
 * @brief Initializes communications, sensors, and system modules.
 * Runs only once when the microcontroller is powered on or reset.
 */
void setup() {
  // Serial port initialization if debugging is enabled in Configuracion.h
#if (DEBUG_LEVEL >= 1)
  Serial.begin(115200);
  // On some boards (like ESP32), it's useful to wait for the serial port to connect.
  while (!Serial) {
    ;  // Wait loop
  }
#endif

  DEBUG_INFO("**********************************************");
  DEBUG_INFO("*       AIRLINK Monitoring System            *");
  DEBUG_INFO("**********************************************");
  DEBUG_INFO("Initializing system...");

  // Initialize the RTC (Real-Time Clock) and periodic alarms
  rtc_alarma_inicializar();

  // Initialize the T6793 sensor
  t6793_inicializar();

  // Initialize the SEN5X sensor
  sen5x_inicializar();

  // Conditional module initialization
#if HABILITAR_NBIOT
  nbiot_inicializar();
#endif

  DEBUG_INFO("Initialization completed. Starting main loop.");
}

/**
 * @brief Runs repeatedly after setup() has finished.
 * This is the heart of the program, where periodic tasks are checked and executed.
 */
void loop() {
  // Check if the 5-second alarm has been triggered to read sensors.
  // This function is non-blocking and based on millis().
  check_alarma_5s();

  // Check if the 10-minute alarm has been triggered to average and send data.
  // This function is based on the RTC clock.
  check_alarma_10min();

  // If the 5-second flag is active, execute the readings.
  if (alarma_5s) {
    DEBUG_INFO("5s alarm triggered. Reading sensors...");

    // Accumulate the read data for later averaging
    acumular_datos();

    // Reset the flag for the next iteration
    alarma_5s = false;
  }

  // If the 10-minute flag is active, execute averaging and transmission.
  if (alarma_10min) {
    DEBUG_INFO("10min alarm triggered. Processing and sending data...");

    // Calculate the average of accumulated readings
    promediar_datos();

// Transmit the averaged data if the module is enabled
#if HABILITAR_NBIOT
    nbiot_enviar();
#endif

    // Reset the flag for the next iteration
    alarma_10min = false;
  }
}

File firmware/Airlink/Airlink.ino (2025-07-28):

/***********************************************************************************************************************
 * @file        Airlink.ino
 * @brief       Código principal para un sistema de monitoreo de calidad del aire ("Airlink").
 * Este programa integra lecturas de diversos sensores y gestiona su funcionamiento
 * a través de temporizadores no bloqueantes (millis). Incluye módulos opcionales
 * para transmisión de datos por NB-IoT y para detección de tos mediante Edge Impulse.
 *
 * @author      [TU_NOMBRE_AQUÍ / ALD-DSL/ATARI-UCA]
 * @date        [2024-07-22 / Última Modificación]
 * @version     1.0
 *
 * @license     Este código fuente (Airlink.ino y los archivos .cpp/.h del proyecto) está licenciado
 * bajo la Creative Commons Attribution-ShareAlike 4.0 International (CC-BY-SA 4.0).
 * Para ver una copia de la licencia, visita: http://creativecommons.org/licenses/by-sa/4.0/
 *
 * @note        Este archivo es el punto de entrada del programa.
 **********************************************************************************************************************/

/***********************************************************************************************************************
 * INCLUSIÓN DE LIBRERÍAS Y MÓDULOS
 **********************************************************************************************************************/
#include <Arduino.h>        // Librería principal de Arduino (funciones básicas como setup, loop, millis). Licencia: LGPL.
#include "Configuracion.h"  // Archivo de configuración central para habilitar/deshabilitar módulos.
#include "Debug.h"          // Contiene las macros para controlar la salida de depuración por Serial.
#include "Alarma.h"         // Módulo propio para la gestión de temporizadores (alarmas periódicas).
#include "SEN5X_API.h"      // API para el manejo del sensor Sensirion SEN5X.
#include "T6793_API.h"      // API para el manejo del sensor de CO2 T6793-5K.

//--- Inclusión condicional de módulos (controlado desde Configuracion.h) ---
#if HABILITAR_NBIOT
#include "Transmision_NBIOT.h"  // Módulo para la transmisión de datos vía Narrowband IoT.
#endif
/*
#if HABILITAR_TOS
#include "Tos.h" // Módulo para la detección de tos usando un modelo de Machine Learning (Edge Impulse).
#endif
*/

#define DEBUG_TAG "MAIN"

/***********************************************************************************************************************
 * FUNCIÓN setup()
 * Se ejecuta una sola vez al encender o reiniciar el microcontrolador.
 * Inicializa las comunicaciones, los sensores y los módulos del sistema.
 **********************************************************************************************************************/
void setup() {
  // Inicialización del puerto serie si la depuración está habilitada en Configuracion.h
#if (DEBUG_LEVEL >= 1)
  Serial.begin(115200);
  // En algunas placas (como ESP32), es útil esperar a que el puerto serie se conecte.
  while (!Serial) {
    ;  // Bucle de espera
  }
#endif

  DEBUG_INFO("**********************************************");
  DEBUG_INFO("*       Sistema de Monitoreo AIRLINK         *");
  DEBUG_INFO("**********************************************");
  DEBUG_INFO("Inicializando sistema...");

  // Inicializa el RTC (Reloj de Tiempo Real) y las alarmas periódicas
  rtc_alarma_inicializar();
  DEBUG_INFO("RTC y Alarmas inicializadas.");

  // Inicializa el sensor T6793
  t6793_inicializar();
  DEBUG_INFO("Sensor T6793 inicializado.");

  // Inicializa el sensor SEN5X
  sen5x_inicializar();
  DEBUG_INFO("Sensor SEN5X inicializado.");

  // Inicialización condicional de los módulos
#if HABILITAR_NBIOT
  nbiot_inicializar();
  DEBUG_INFO("Módulo NB-IoT inicializado.");
#endif
  /*
#if HABILITAR_TOS
  inicializar_tos();
  DEBUG_INFO("Módulo de Detección de Tos inicializado.");
#endif
*/
  DEBUG_INFO("Inicializacion completada. Iniciando bucle principal.");
}

/***********************************************************************************************************************
 * FUNCIÓN loop()
 * Se ejecuta repetidamente después de que setup() ha terminado.
 * Es el corazón del programa, donde se comprueban y ejecutan las tareas periódicas.
 **********************************************************************************************************************/
void loop() {
  // Comprueba si se ha activado la alarma de 5 segundos para leer los sensores.
  // Esta función es no bloqueante y se basa en millis().
  check_alarma_5s();

  // Comprueba si se ha activado la alarma de 10 minutos para promediar y enviar datos.
  // Esta función se basa en el reloj RTC.
  check_alarma_10min();

  // Si la bandera de 5 segundos está activa, ejecuta las lecturas.
  if (alarma_5s) {
    DEBUG_VERBOSE("Alarma 5s activada. Leyendo sensores...");

    // Acumula los datos leídos para su posterior promedio
    acumular_datos();

    // Reinicia la bandera para la siguiente iteración
    alarma_5s = false;
  }

  // Si la bandera de 10 minutos está activa, ejecuta el promedio y la transmisión.
  if (alarma_10min) {
    DEBUG_INFO("Alarma 10min activada. Procesando y enviando datos...");

    // Calcula el promedio de las lecturas acumuladas
    promediar_datos();

// Transmite los datos promediados si el módulo está habilitado
#if HABILITAR_NBIOT
    nbiot_enviar();
#endif

    // Reinicia la bandera para la siguiente iteración
    alarma_10min = false;
  }

  // Ejecuta el bucle de inferencia para la detección de tos, si está habilitado.
  // Esta función debe ser llamada tan frecuentemente como sea posible.
#if HABILITAR_TOS
  loop_tos();
#endif
}

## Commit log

2025-07-28 Add Airlink exploded and PCB images
    Added two new images to the documentation: an exploded view and a PCB view of the Cicerone Airlink. These images will help clarify hardware details for users and developers.
2025-07-29 Update license in firmware documentation
    Replaced the GNU Free Documentation License with the GNU General Public License v3 in docs/about/lic-firmware.md to accurately reflect the licensing of firmware. Added license information headers to multiple documentation files for clarity and compliance.
    [CICERONE AirLink PCB v53.csv, CICERONE AirLink PCB v53.dxf, cicerone-airlink-case-bottom.step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]
2025-07-30 Update AirLink PCB to v57 and refresh hardware files
    Renamed and updated PCB assembly and drawing files to version 57, replaced outdated PDF and added new schematic and board files. Updated Gerber, drill, and ODB files, refreshed image assets, and fixed documentation image link to use an absolute URL.
    [CICERONE AirLink v57.csv, CICERONE AirLink v57.dxf, CICERONE AirLink.brd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]
2025-08-15 Refactor sensor APIs and update Doxygen config
    Improved documentation and comments for DS3231M, SEN5X, and T6793 sensor APIs. Updated debug messages and logging levels for better clarity. Removed redundant license and reference blocks from header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
2025-08-16 updated hardware files
    [Airlink Case - Bottom.f3d, Airlink Case - Bottom.step, Airlink Case - Top.f3d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]
2025-08-21 Add Arduino.h includes and fix format specifiers
    Added #include <Arduino.h> to multiple header files for compatibility. Fixed format specifiers in DEBUG_INFO and DEBUG_VERBOSE calls for correct data types. Removed unused variables and functions, and corrected return statements in T67XX.cpp. Updated .gitignore to exclude firmware/build directory.
    [DS3231M.cpp, SEN5X_API.cpp, T67XX.cpp]
2025-08-21 Refactor Doxygen config and update .gitignore
    Moved Doxyfile and DoxygenLayout.xml to .doxygen directory and updated paths to use relative references for portability. Enhanced .gitignore to better handle build artifacts, logs, and temporary file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
2025-08-21 Add VSCode config and generated firmware docs
    Added initial .vscode configuration files for Arduino development. Generated firmware documentation files were added under docs/firmware/html, and the Doxygen configuration file was moved to the proj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
2025-10-15 docs: configure dual-language API documentation system
    - Add Doxyfile_es for Spanish firmware documentation (firmware_es/)
    - Rename Doxyfile to Doxyfile_en for English firmware documentation
    - Integrate mkdoxy plugin in mkdocs.yml with bilingual support:
    * es/firmware project → firmware_es/ source directory
    * firmware project → firmware/ source directory
    * Configure FILE_PATTERNS, RECURSIVE, EXTRACT_ALL, EXCLUDE settings
    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
2025-10-16 docs: enhance documentation with complete user guides
    docs: enhance documentation with complete user guides
    Add comprehensive guides for firmware configuration, debug system, and architecture. Enhance AUTHORS.md with CRediT taxonomy and contribution matrix. Create CONTRIBUTING.md with detailed guidelines. 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
2025-10-16 docs(firmware): reorganize documentation into modular structure
    Split firmware/index.md into 4 specialized documents (architecture,
    program-flow, sensor-interfaces, data-transmission) plus concise
    landing page with Material MkDocs navigation cards.
    - Add firmware documentation modules (320-569 lines each)
    - Transform index.md into navigation hub (234 lines)
    - Add .nav.yml files for firmware/ and user-guide/
    - Update mkdocs.yml to organize API docs in firmware/api/
    - Fix markdown linting issues across all documentation
    - Improve line length and formatting consistency
    BREAKING CHANGE: API docs moved to /firmware/api/
2025-10-16 docs: fix typos and standardize battery specifications
    - Fix typos: "Comunication", "Seed Studio", "a embedded"
    - Unify battery life to "~5 hours" (was "4-6 hours" in firmware docs)
    - Standardize battery format to "900 mAh" with space
2025-10-17 docs: update BOM table and fix typos across documentation
    - Update component cost table in other-information.md with official BOM data
    - Add missing components: standoff, rocker switch, cable gland
    - Fix typos: 'Comunication' → 'Communication' in README.md
    - Fix typos: 'Seed Studio' → 'Seeed Studio' in electronics.md
    - Fix grammar: 'a embedded' → 'an embedded' in description/index.md
    - Standardize battery life to '~5 hours' across all documentation
    - Standardize battery format to '900 mAh' (with space)
    - Update total cost: 130.59 € → 130.71 €
    - Add assembly images and update assembly guide
    - Configure markdownlint to ignore copilot-instructions.md
    Improves consistency and accura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
2025-10-17 fix: assembly images
2025-10-20 fix: update image paths in assembly documentation
2025-10-21 fix: renamed assembly images for documentation
2025-10-21 fix(ci): enable Git LFS support in mkdocs deployment workflow
    - Add lfs: true to checkout action
    - Add explicit git lfs pull step
    - Fixes assembly images showing as 131-byte LFS pointers instead of actual images
    - Resolves 404/broken image issues on GitHub Pages

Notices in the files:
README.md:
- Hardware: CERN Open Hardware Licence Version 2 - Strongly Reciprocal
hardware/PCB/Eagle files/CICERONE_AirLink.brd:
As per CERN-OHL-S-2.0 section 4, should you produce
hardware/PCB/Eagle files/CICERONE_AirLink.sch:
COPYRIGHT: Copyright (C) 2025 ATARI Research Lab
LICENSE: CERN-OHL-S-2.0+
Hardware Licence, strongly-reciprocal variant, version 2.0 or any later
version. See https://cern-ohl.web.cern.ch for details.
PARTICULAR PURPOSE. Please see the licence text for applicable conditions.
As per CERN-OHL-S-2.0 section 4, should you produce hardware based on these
